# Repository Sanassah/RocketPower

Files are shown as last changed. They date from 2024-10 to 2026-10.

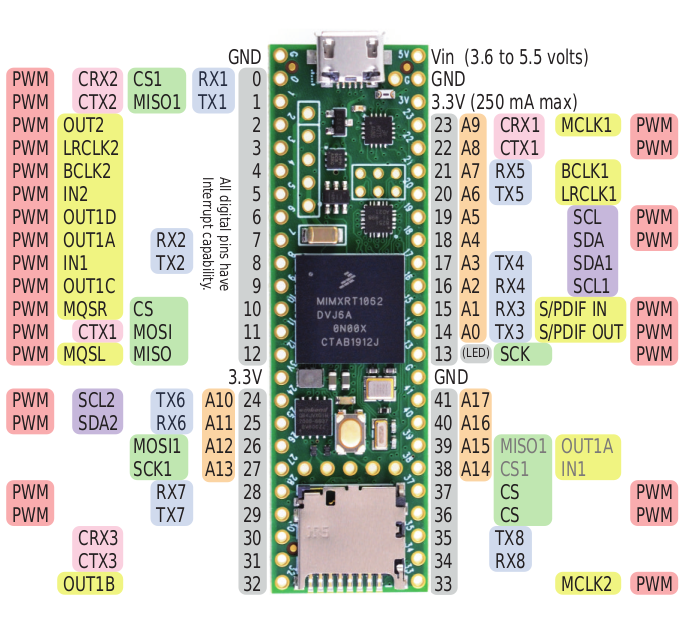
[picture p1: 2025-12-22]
Documentation/TechnicalDoc/Teensy4.1_Pinout.png

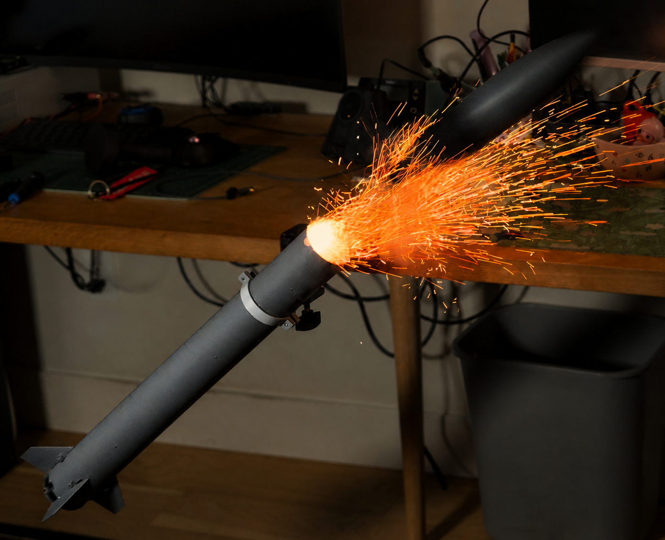
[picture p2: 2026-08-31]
Media/Linkedin_Post2/ThumbnailLinkedInpost2.png

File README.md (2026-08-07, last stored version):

<div align="center">

# 🚀 RocketPower

### A ground-up model rocket build — PCB design, CAD, systems simulation, and control systems.

RocketPower rocket render






</div>

---

## About

This is where I track progress on a model rocket build — avionics included — showcasing work in PCB design, CAD, systems simulation, and control systems.

**[→ Flight Procedure](./FLIGHT_PROCEDURE.md)** — step-by-step instructions for bench checkout, arming, launch, recovery, and post-flight data review, plus hardware-in-the-loop testing before you fly.

---

## Media

<!-- Swap these placeholders with real captures as the build progresses -->

Watch the launch (https://youtube.com/watch?v=PLACEHOLDER)

<p float="left">
  
  
  
</p>

---

## Build Log

| Date | Milestone |
|---|---|
| 2025 | Flight computer schematic complete |
| June 2026 | First avionics bench test |
| TBD | First flight |

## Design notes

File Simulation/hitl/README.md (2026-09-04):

# HITL (hardware-in-the-loop) testing

Runs the **real, compiled** flight firmware — `StateMachine`, `BackupDeploy`,
`AttitudeController`, `FinController`, `PyroController`, all byte-identical
to the flight build — on the actual Teensy 4.1, fed synthetic sensor data
from `RocketPowerSim.slx`'s 6DOF/aero model in real time, with the real fin
commands it computes closing the loop back into the simulated aero/actuator
response. This is what `config.h`'s pre-flight checklist means by "validated
in simulation (closed-loop)" before ever sending `ATTITUDE_CONTROL_ENABLE`
for a real flight — open-loop telemetry replay can't test this because
there's nothing for a replayed fin command to act on.

**One model, one switch.** `RocketPowerSim.slx` handles both plain
simulation and HITL now — double-click the **"HITL Mode Select"** Manual
Switch on the canvas to flip between them. It defaults to Normal Sim (no
hardware needed, same behavior as before HITL existed); flip it to HITL
only when you actually want a Teensy in the loop.

## What's real vs. simulated (in HITL mode)

| | Real | Simulated |
|---|---|---|
| Control code (state machine, attitude PID, fin allocation/clamping, pyro logic) | ✅ actual Teensy, actual compiled firmware | |
| Sensors (IMU, baro, high-g accel) | | ✅ injected over serial, from the 6DOF plant |
| Rigid-body dynamics, aero, servo lag/rate-limit | | ✅ `RocketPowerSim.slx`, unmodified downstream of the switch |
| Fin servos, pyro MOSFETs, SD card, LoRa | ✅ real hardware (harmless on a bench with no ematches/props attached) | |

## One-time setup

1. Flash the HITL build (not the flight firmware):
   ```
   cd FlightComputer
   pio run -e rocketpower_hitl -t upload
   ```
   This is a separate PlatformIO environment (`platformio.ini`) — the
   default `rocketpower` env (real flight firmware) is untouched by any of
   this.
2. Find the Teensy's **second** USB serial port (`SerialUSB1` on the device
   side) in Device Manager — it shows up as a second "USB Serial Device"
   alongside the one you already use for the ground station. The first port
   still carries normal command RX and the existing telemetry mirror
   completely unmodified — you can have the real GroundStation app
   connected over it and watch a HITL run live at the same time.
3. Open `RocketPowerSim.slx`, go inside the **"HITL Bridge"** subsystem,
   double-click `TeensyBridge`, and set `ComPort` to that second port.

## Running

- **Plain simulation**: leave "HITL Mode Select" at its default (Normal
  Sim) and run the model exactly as before — nothing about this changed,
  no hardware involved, same speed.
- **HITL**: double-click "HITL Mode Select" to flip it to HITL, then run.
  It runs in **real time** — `TeensyBridge` paces itself to wall clock
  every step, because the firmware's own safety timing (liftoff-confirm,
  apogee-detect window, backup-fire delay) is driven by the Teensy's
  hardware `millis()`, which nothing here can override (see the header
  comment on `SensorInjectPacket` in
  `FlightComputer/src/telemetry/Packet.h`). A 30s simulated flight takes
  ~30s.

`tout`/`pos_log`/`q_log` land in the base workspace exactly like before, so
`animate_flight.m` works unchanged either way.

To exercise ARM → liftoff → apogee → landed in HITL, send the same
`ARM`/`DISARM`/`FIRE_PYRO` commands you'd use from the ground station, over
the Teensy's **first** serial port, at whatever point in the run you want
them to take effect — the state machine reacts to them exactly as it would
in flight. Active fin control is a separate opt-in from ARM — send
`ATTITUDE_CONTROL_ENABLE` (works any time before liftoff, survives ARM) or
`ATTITUDE_DEMO_ENABLE` (takes effect in `IDLE` or `ARMED`, no need to arm
first) if you want the fins to actually respond.

### Debug scopes (inside "HITL Bridge")

- **"HITL Firmware State"** — the real firmware's own `FlightState` this
  step (`0`=IDLE, `1`=ARMED, `2`=POWERED_ASCENT, `3`=COAST, `4`=APOGEE,
  `5`=DESCENT, `6`=LANDED, `-1`=no response yet). Scope it alongside
  `rollCmd`/`pitchCmd`/`yawCmd` (`HITL Bridge`'s own outputs, or tap them
  where they feed the `Mode Switch N` blocks at the top level) if a command
  looks like it's still moving when you think it shouldn't be — this
  model's scopes plot against *simulation* time, while GroundStation's
  display is timestamped off the Teensy's own `millis()`, so
  cross-referencing "what I saw in GroundStation" against a Simulink
  scope's x-axis isn't reliable. The state output settles that directly: a
  command can only still be actively changing while state reads `2`
  (`POWERED_ASCENT`) or `3` (`COAST`).
- **"HITL Sensors (highg, tiltDeg, altitude, vertVel, gyro)"** — the raw
  plant-side signals `TeensyBridge` derives from the sensor stream:
  `highg` (1x3, g's, the exact specific-force vector sent to the firmware
  — same thing `StateMachine`/`BackupDeploy` threshold on via its
  magnitude), `tiltDeg` (angle from identity quaternion, not necessarily
  "from vertical" — see `TeensyBridge.m`'s class header), `altitude` (m,
  up-positive), `vertVel` (m/s, up-positive), `gyro` (1x3 rad/s). Valid
  every step regardless of whether the firmware actually responded, since
  they're computed straight from the injected sensor state, not the reply
  — useful for isolating a plant/physics issue from a firmware/control-loop
  one (e.g. watching whether `highg`/`tiltDeg` misbehave the same way even
  with `ATTITUDE_CONTROL_ENABLE` never sent, which points at
  `RocketPowerSim.slx`'s own aero model rather than anything in
  `FlightComputer/`).

## How the bridge works (`TeensyBridge.m`)

Lives inside the **"HITL Bridge"** Enabled Subsystem (quat/gyro/Xe in,
roll/pitch/yaw out), which only actually runs while "HITL Mode Select" is
set to HITL — see "Why an Enabled Subsystem" below for why that matters.
Each discrete step (default `Ts = 0.01s`, matching the firmware's real
100Hz loop):
1. Paces to wall clock.
2. Packs quaternion + body rate + position (derived from the `6DOF
   (Quaternion)` block's outputs — see the port mapping below) into a
   `SensorInjectPacket` and writes it to the Teensy.
3. Blocks for one `HITLResponsePacket` back — the real firmware's actual
   decision, fin clamping included.
4. Recovers pre-allocation roll/pitch/yaw commands from the 4 real per-fin
   degrees (`CH1=S, CH2=E, CH3=N, CH4=W` — see `AttitudeController.h`).

At the top level, each axis has a `Switch` block picking between "HITL
Bridge"'s recovered command and the model's own original PID output
(`Sum`/`Sum2`/`Sum3`), controlled by the same "HITL Mode Select" signal —
either way the result feeds the same actuator chain (`15deg sat` →
`1000deg/s` → `Servo lag (τ=15ms)` → moment/aero chain), unchanged.

### Why an Enabled Subsystem, not just a switch downstream

`TeensyBridge` opens its serial port **lazily**, on its first real
`stepImpl()` call, not in `setupImpl()`. This was a deliberate fix, and
matters if you ever restructure this: `matlab.System`'s `setupImpl` runs
once during Simulink's initialization phase for **every** block in the
diagram, *including* ones inside a currently-disabled Enabled
Subsystem — confirmed empirically. An Enabled Subsystem's enable signal
only gates `stepImpl`, not one-time setup. So if the port were opened in
`setupImpl` instead, a plain Normal Sim run would still require the Teensy
plugged in and running `rocketpower_hitl`, defeating the entire point of
the switch. Wrapping "HITL Bridge" in an Enabled Subsystem (rather than
just switching its output downstream, with the subsystem always running)
is what makes `stepImpl` — and therefore the port-open — only ever happen
when actually enabled.

### "roll"/"pitch"/"yaw" axis convention

This model (see `Constants.m`'s own header comment, `"spin about z = your
'yaw'"`) uses a **drone-style** convention: `"roll"` and `"pitch"` are the
two transverse-tilt channels (`Fin Moment Arm Roll`/`Pitch`, gain
`Cn_alpha`), and `"yaw"` is spin about the rocket's own longitudinal axis
(`Rocket Diameter2`, gain `Cl_delta` — confirmed by tracing each `*deg sat`
block forward to its moment-arm gain).

`FlightComputer/src/config.h`/`AttitudeController.cpp` use this SAME
convention (previously they used the opposite, standard-aerospace one,
where "roll" is the spin axis) — see config.h's axis-naming comment above
the `ATTITUDE_ROLL_RATE`/etc. macros. So each `Mode Switch N` block wires
`HITL Bridge` output `i` to actuator row `i` — a plain name-to-name mapping
is correct.

**This matters if you ever touch either side's axis convention again**: a
same-named-but-wrong mapping is silently wrong, not an error — it applies
the firmware's spin correction as a tilt moment and one of its tilt
corrections as a spin moment, so the controller can never actually reduce
the real error on 2 of 3 axes. That looked exactly like "the controller
won't converge" (saturating, growing commands), with no error thrown
anywhere. If you rename an axis on either side, re-derive whether the
mapping needs to go back to an explicit physics-based remap instead of
row-to-row.

### `6DOF (Quaternion)` output port mapping

Not documented anywhere in the model — empirically confirmed by probing a
live run against `Constants.m`'s own `eul_0`/`pm_0` initial conditions
(out3 matched `eul_0` exactly; out7 matched `pm_0` exactly; out4 matched
the quaternion equivalent of `eul_0`'s rotation) and, separately, by
differentiating every 3-wide output against every other over a real
flight:

| Port | Signal | Used by the bridge? |
|---|---|---|
| out1 | `Ve` — world-frame **velocity** (confirmed: `d(out2)/dt ≈ out1` almost exactly over a full flight) | not used directly |
| out2 | `Xe` — position `[x y z]`, m. **`Xe(3)` is UP-positive** (confirmed empirically against a full ascent/descent run — apex altitude and a clean positive→negative vertical-velocity crossing right at apex). This is *not* the NED Z-down convention `animate_flight.m`'s own `alt = -pos(:,3)` comment describes for `pos_log` — that variable evidently goes through additional processing this bridge doesn't touch (it taps out2 directly) | ✅ → altitude (`Xe(3)`, no negation); differentiated twice (world velocity, then world acceleration) for `vertVel` and body-frame kinematic accel |
| out3 | Euler angles, rad | not used |
| out4 | quaternion `[w x y z]` | ✅ → `quat_w/x/y/z`; also used to rotate world-frame quantities (acceleration, gravity) into body frame |
| out5 | DCM (quaternion→DCM) | not used |
| out6 | `Vb` — body-frame velocity | not used |
| out7 | `Wb` — body angular rate, rad/s | ✅ → `gyro_x/y/z` |

**The `6DOF (Quaternion)` block has no acceleration output at all.** Body-
frame kinematic acceleration is derived by the bridge itself: double-
differentiate `Xe` (world position) to get world-frame acceleration, then
rotate into body frame with the quaternion via `quatRotateWorldToBody.m`
(the same helper used for gravity, below). This replaced an earlier,
wrong version of this bridge that fed `out1` in as if it were acceleration
— it isn't, it's velocity, and using it as acceleration meant the firmware
was receiving a velocity value mislabeled as `lin_accel`/used for `highg`
for a while. If you ever add a new signal from this block, verify what it
actually is (e.g. by differentiating it against known IC's or another
candidate) rather than trusting a name or a guess — this model doesn't
label its own ports.

Gravity in this same world frame is `[0;0;-g]` (pulls toward -Z, matching
the "+Z is up" finding above) — used to project gravity into body frame for
`highg`. Getting this wrong doesn't just flip `highg`'s per-axis sign, it
corrupts its **magnitude** too whenever the airframe isn't sitting still or
perfectly vertical (the kinematic-accel and gravity-projection vectors stop
being parallel), and magnitude is exactly what `StateMachine`/
`BackupDeploy` threshold on (`highg_mag_g`) — see
`quatRotateWorldToBody.m`'s header.

**Getting the altitude sign wrong is a silent, nasty failure mode**, not a
crash: it doesn't break liftoff detection (that's magnitude-only), but it
inverts the sense of `COAST`'s zero-crossing check, so a real ascent-to-
descent transition reads as vert_vel going negative→positive instead of the
positive→negative the firmware is watching for. The state machine then gets
stuck in `COAST` for the rest of the flight, however long it runs, with no
error anywhere — it looks exactly like "the state machine isn't working"
rather than "the plant-side sign is backwards." If a flight visibly climbs
and comes back down but `state` never leaves `COAST`, check this first.

## Troubleshooting

- **"nothing on the dashboard" in GroundStation, even though it's
  connected**: make sure you're connected to the Teensy's *first* USB
  serial port, not `SerialUSB1`. Also make sure you reflashed after any
  firmware update — `SensorManager::update()` falls back to a safe
  "resting on the pad" default and keeps the loop (and telemetry) running
  even before `TeensyBridge` connects.
- **`Function 'serialport' not supported for code generation` when running
  the model**: `TeensyBridge` must run in interpreted execution, not the
  MATLAB System block's default code-generation mode. Double-click it
  (inside "HITL Bridge"), open its block parameters, and set "Simulate
  using" to "Interpreted execution".
- **A HITL run seems to hang, or errors immediately about a port**: check
  `TeensyBridge`'s `ComPort` (inside "HITL Bridge") actually matches the
  Teensy's *second* port right now — it can change across replugs/reflashes.
  The error message lists what's actually available if it can't find it.
- **Started a HITL run, want to go back to plain simulation**: just flip
  "HITL Mode Select" back and rerun — no other cleanup needed.

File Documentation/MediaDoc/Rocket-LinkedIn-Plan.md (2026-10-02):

# RocketPower — LinkedIn Posts

4 posts. Post 1-3 are ready now. Post 4 is reserved, write it after the
actual flight (two branches below, use whichever happened). Only the
`[MEDIA: ...]` lines (and the `[DATE]`/`[X]` fields in post 4) are
placeholders.

---

## Post 1

In 2024, I started designing a custom flight computer for a rocket 🚀
Then I didn't touch it again for almost a year.

My capstone project was a drone built from scratch with a great team.
When it ended, I missed the challenge, so I leaned on my background in
rocketry at Concordia and started something of my own: an active
fin-control rocket, custom PCB and flight control code in C++. I got as
far as the MCU section of the schematic before life took over.

Graduation, a trip through Asia, a new job, moving out of my parents'
house. A year passed. I'd open KiCad, feel discouraged by the amount of
work ahead, and close my laptop.

The itch never went away, and I came back to it in 2025. I bought a $200
refurbished 3D printer, a soldering station, and a power supply. I had to
relearn electronics from books, forums, YouTube, and PJRC. I often felt
the need to go on Fiverr and hire an EE for a review of my work, but I
decided to trust myself, and earned that trust through 15 revisions 😆

Then came the layout, the hardest part. Fitting that many sensors, servo
channels, telemetry, camera, GPS, EMI shielding, power conversion, and
pyro channels into a 50mm diameter was the challenge, I wasn't willing to
compromise. I picked a BGA MCU (MIMXRT1062) on purpose, smaller footprint
and more of a headache. A 2-layer board wouldn't work. I went to 4 layers
and rewrote the whole architecture more than once. There were nights I
stared at the ratsnest wondering if I'd picked a form factor that just
didn't work.
Then, at some point, it did.

[MEDIA: photo of the $200 refurb 3D printer / solder station setup or the
early schematic, plus a PCB layout screenshot showing the density]

#engineering #aerospace #pcbdesign #embeddedsystems

---

## Post 2

The preassembled board finally arrived ($400 later). It was pure magic right up until I plugged it in... then crickets. 
Total radio silence: no COM port, no USB handshake, no signs of life.

I'd ordered it through PCBWay, generated the Gerbers while vacationing in Peru, and managed supplier Q&A from 
there (really impressed by their service btw). But one design mistake at that stage meant flushing money and effort down 
the drain. So when it showed up dead, my stomach dropped.

Cue two nights of full-blown engineering existential dread. At one point, I was staring down the barrel of manually 
reworking microscopic BGA pads. But after sleeping on it, I stopped overthinking and audited the schematic line by line.

Turns out, I didn't need surgical BGA mastery. I had accidentally designed the reset button to be hard-wired to ground. 
Basically, I gave my own flight computer a perpetual coma. One quick trace surgical strike with an X-Acto knife later, 
I plugged it in and heard the glorious Windows USB connect chime. I don't think a single sound has ever brought me that much inner peace.

[MEDIA: macro shot of the knife-cut trace on the real board, plus a photo
of the board arriving/unboxing]

#pcbdesign #embeddedsystems #debugging

---

## Post 3

While the board was busy pretending to be dead, the rest of the rocket had
to keep moving in parallel.

Fusion 360: carbon fiber rods, a 3D-printed body, 4.4g servos on
3D-printed fins, all self-taught, including the hard way why revision
control matters (RIP a few corrupted CAD files).

Procurement became its own side-quest, motors, cameras, LiPos, ejection
charges, e-matches, telemetry, while I built the ground station in
parallel: the classic "one quick fix" that ends at 3AM with the terminal
staring back. Sensors blinked to life one by one, each a small dopamine
hit, minus the time I shorted a connector and blew a fuse (protection
circuitry: confirmed working).

The real test was 6DOF simulation in Simulink, real mass/CG/CP from
Fusion and OpenRocket, tuning fin control before the flight computer ever
touched real hardware. Handling the airframe also exposed a flimsy
direct-drive fin mount, fixed with a tiny press-fit bearing, and pushed
me to make the fins fail safe on a dead servo.

Then hardware-in-the-loop: real flight computer, real control code, wired
straight into the simulation. Watching the 6DOF animation and the ground
station agree on every flight phase live was the best moment of this
project yet. Honest caveat: no RTOS, so a stray SD card hiccup at the
wrong moment is a risk I'm flying with, eyes open.

The whole thing is assembled and sitting in front of me. Still doesn't
feel real.

Next up: finding a launch site. To be continued.

[MEDIA: 20s HITL + ground station video (see PreflightVideo-ShotList.md)
as the primary post video, plus a close-up photo of the bearing mod as a
secondary image if LinkedIn's carousel allows more than one attachment]

#cad #groundstation #hitl #controlsystems #aerospace

---

## Post 4 (write after the actual flight, use whichever branch happened)

**If it flew clean:**

[DATE]. After [X] months of nights, the rocket flew.

Custom flight computer, custom PCB, active fin control, hand-built ground
station, all of it ran like it did on the bench, just [X]m up instead of
on a table.

Apogee at [X]m, recovery [X]m from the pad. Every system worked.

Two years ago this was a notebook sketch. Today it's a flight log.

**If something went wrong:**

[DATE]. The rocket flew today, and it didn't go the way I planned.

[ONE OR TWO SENTENCES: what happened]

I'll tell that story in full, it's more useful than a highlight reel, and
everything else in this project failed once before it worked too.

[MEDIA: launch photo/video, ignition, ascent, recovery, plus a screenshot
of the actual telemetry plot from the flight]

#aerospace #rocketry #embeddedsystems

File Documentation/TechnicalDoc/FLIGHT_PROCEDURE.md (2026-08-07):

# Flight Procedure

Step-by-step operating instructions for the RocketPower flight computer and
ground station — bench checkout, pad procedure, launch, recovery, and data
review. For code/architecture docs see `FlightComputer/` and
`GroundStation/README.md`; this file is about *running* the system, not how
it's built.

---

## 0. What you're working with

- **Flight computer**: custom PCB (`FlightComputer/`), programmed via the
  Teensy 4.1 toolchain. Runs autonomously once powered — it does not need
  the ground station connected to fly correctly. The ground station is for
  visibility and manual commands (arm, fire, calibrate), not for the flight
  logic itself.
- **Ground station** (`GroundStation/`): the PyQt6 app (`python main.py`).
  Three pages, left sidebar: **OVERVIEW** (GPS map, trajectory, 3D
  orientation, pyro/continuity/arm panels), **TELEMETRY** (sensor status,
  commands, event log), **DATA TOOLS** (post-flight `.BIN` → CSV/MATLAB
  converter).
- **Two ways to connect the ground station**: directly via USB to the
  flight computer (bench testing — fast, but only works with a cable
  attached), or via a ground-side LoRa receiver dongle at **9600 baud**
  (the actual flight link, works untethered). Pick the right COM port/baud
  in the sidebar before connecting.

---

## 1. Bench checkout (do this before you ever go to the pad)

1. Flash the real flight firmware if you haven't recently:
   ```
   pio run -e rocketpower -t upload
   ```
2. Power the flight computer and let it boot. It self-tests every sensor
   and the SD card, then halts (flashing the status LEDs) if the IMU or
   barometer failed — those two are flight-critical and it won't proceed
   without them. Everything else (GPS, accelerometer, power monitor, SD)
   is allowed to fail at boot and just gets flagged, not fatal.
3. Connect the ground station over USB and open the **TELEMETRY** page.
   Check the **STATUS** section: IMU / Barometer / Accelerometer / GPS
   Module / Power Monitor should all read **OK**, and **SD Card** should
   read **IDLE** (present, not yet recording — recording starts
   automatically once you arm, see §3) or **RECORDING** if a card was
   present at boot (it auto-opens a log immediately, see §4).
   - If SD reads **NO CARD**: insert one and press **Start Log** in the
     SD CARD section of the command panel to retry — it doesn't
     re-poll on its own (see `DataLogger::cardPresent()`'s doc comment
     for why).
4. Check pyro continuity on the OVERVIEW page's continuity panel — each
   channel should show continuity if an ematch is connected (or "open" if
   deliberately left disconnected for a bench test).
5. Optional: run a fin servo preflight sequence (TELEMETRY page → FIN
   SERVOS section → **PREFLIGHT**) to visually confirm all 4 channels move
   correctly before you close up the airframe.
6. Optional: toggle the camera on/off once (CAMERA section) to confirm the
   UART link is alive — it also self-probes at boot and reports to Serial.

---

## 2. Pad procedure

1. Mount the rocket vertically on the pad, **stationary** — the next step
   calibrates the barometer against whatever altitude it's sitting at
   right now, so don't move it after this point.
2. Connect the ground station via the LoRa link (not USB, unless you're
   doing a tethered test) and confirm telemetry is flowing (state should
   read **IDLE**, sensor values should look sane, GPS should have a fix if
   you want position data during descent/recovery).
3. Press **ARM** (ARM CONTROL section, or the dedicated arm panel on
   OVERVIEW). This asks for confirmation, then:
   - Arms the pyro channels (fire commands only work while armed).
   - Re-calibrates the barometer at the pad — this is why the rocket needs
     to be stationary and already in its final position.
   - Starts the camera recording, if not already running.
   - SD logging is already running by this point (started automatically at
     boot) — arming doesn't gate it, it's just confirmed by the SD status
     row.
4. Double check the SD status row now reads **RECORDING** and pyro
   continuity still looks correct before proceeding — this is your last
   easy checkpoint before the log starts mattering.

---

## 3. Launch

- If your motor uses **electronic ignition**: press **Fire CH 1 —
  Ignition** in the IGNITION CONTROL section. This is a real, irreversible
  action (confirmation dialog says so) — it's the actual launch trigger.
- If you're hand-lighting the motor: ARM is still required first (it's
  what enables liftoff detection and parachute deployment logic), but
  ignition itself happens outside the electrical system.

From here the flight computer runs itself — you're a spectator with an
abort/backup option (§5), not a pilot.

---

## 4. What happens automatically in flight

The state machine (`StateMachine.cpp`) transitions on its own based on
sensor data, no ground input needed:

| Transition | Trigger |
|---|---|
| ARMED → POWERED_ASCENT | High-g accel > 2.5g, held for 100ms (liftoff) |
| POWERED_ASCENT → COAST | High-g accel drops below 1.0g (burnout) |
| COAST → APOGEE | Vertical velocity crosses from + to -, held for 200ms |
| APOGEE → DESCENT | Immediate — parachute (CH2) fires automatically here |
| DESCENT → LANDED | Altitude stable within 2m for 10 continuous seconds |

Also automatic: the camera stops recording on LANDED, the SD log flushes
on every state change (bounding data loss) and closes fully on LANDED,
and telemetry keeps transmitting at 1Hz over LoRa the whole time
regardless of what the ground station is doing.

---

## 5. If something looks wrong mid-flight

- **Parachute didn't seem to deploy** (altitude/velocity on the ground
  station not showing a slow-down after apparent apogee): press
  **Fire CH 3 — Backup** manually. This works any time after ARM, not
  just during DESCENT — it's a manual override independent of the state
  machine.
- **Telemetry drops out**: the flight computer doesn't care — it keeps
  flying/logging/recording regardless of whether the ground station is
  receiving. Nothing to do but wait for the link to come back (or recover
  by GPS coordinates / last known position).

---

## 6. Recovery and data review

1. Retrieve the rocket. The SD log is already closed and safe (closed
   automatically on LANDED) — no need to power it off first, but do so
   before opening the airframe to swap the card.
2. Pull the SD card, find the newest `FLTxxxxx.BIN` file.
3. Convert it for analysis — either:
   - **Ground station GUI**: DATA TOOLS page → Browse → select the file →
     check CSV and/or MATLAB → **Convert & Save As...**.
   - **Command line**: `python GroundStation/tools/log_convert.py FLTxxxxx.BIN`
     (writes CSV and, if `scipy` is installed, `.mat` next to the input
     file by default).
4. The ground station's own local CSV log (separate from the flight
   computer's SD card — see the "⏺ REC" button in the TELEMETRY page's
   event log header) captured whatever telemetry it received live, useful
   as a cross-check but lower rate/resolution than the onboard SD log.

---

## Quick troubleshooting

| Symptom | Likely cause |
|---|---|
| FC halts at boot, LEDs flashing | IMU or barometer failed — check wiring/power before anything else |
| SD status stuck on "NO CARD" after inserting one | It doesn't auto-repoll while idle (by design — see §1.3); press **Start Log** |
| Telemetry rate unstable / bounces to 0 | Check `USB_SERIAL_BINARY_MIRROR`/reflash status if using USB |
| USB shows no telemetry at all | `USB_SERIAL_BINARY_MIRROR` must be `1` in `config.h` for a direct-USB ground station connection |
| Ground station won't connect | Right COM port? Right baud (9600 for the LoRa dongle, doesn't matter much for direct USB)? |

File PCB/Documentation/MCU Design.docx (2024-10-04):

SCSD-LP-EPS-004-A

# MCU Design

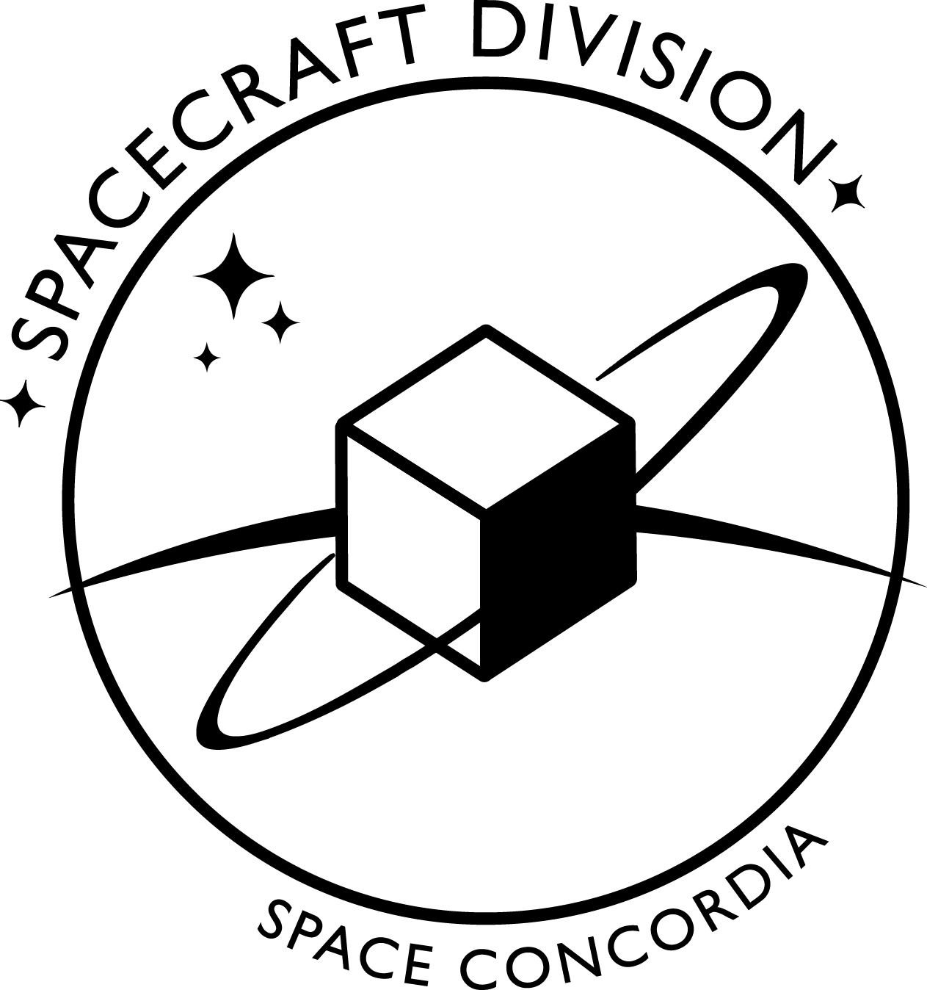
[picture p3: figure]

Prepared by

Gabriel Dubé

Electrical and Power System Lead

Feb 1, 2023

# Revision History

Date | Revision | Changes
5-Feb-2023 | A | Initial Release

# Table of Contents

Revision History 2

Table of Contents 3

References 4

Abbreviations and Definitions 5

Introduction 6

MCU 7

Power 7

Crystals 13

Internal Peripherals 14

GPIOs 15

I/O Isolator 16

Debugging 18

PCB Layout 24

Appendix A 24

# References

[1] CCP- Subsystems - POWER - Design - SC-ODIN-100, Spacecraft Electronics - SPEAR-M7 - Rev A [internal document on Google Drive], “SCH-SCSD20-EPS-001-A”. Available from: https://drive.google.com/file/d/1Hjo98G_CQyjNqB3IPMDdYu_njFDT6Aj3/view?usp=sharing

[2] Marki - RFTOOLS [website], “LC Filter Design Tool”. Website link: https://rf-tools.com/lc-filter/

[3] CUBICS - ELEC - Learning Resources - Learning Package [internal document on Google Drive], “Power”. Available from: https://docs.google.com/document/d/1pKWWyXrTBQWnoESd13gtv7d2UHne3ekIcaZ94zOk2eo/edit?usp=sharing

[4] CUBICS - ELEC - Learning Resources - Learning Package [internal document on Google Drive], “Peripherals Design”. Available from: https://docs.google.com/document/d/1Y1tGknWdWDa7ZUS9X4p9ahikzXoImTVWvahNcEV4DlE/edit?usp=sharing

[5] Microchip datasheet, [PDF document], “SAM E70/S70/V70/V71 Data Sheet”. Link to document: https://ww1.microchip.com/downloads/aemDocuments/documents/MCU32/ProductDocuments/DataSheets/SAM-E70-S70-V70-V71-Family-Data-Sheet-DS60001527.pdf

[6] CUBICS - ELEC - Design [internal document on Google Drive], “Breakout Boards”. Available from: https://drive.google.com/drive/folders/1IolXB_eUfjbBWtSN64kAr6lkOlDXZvvk?usp=share_link

[7] CUBICS - ELEC - Learning Resources - Learning Package [internal document on Google Drive], “Serial Communication”. Available from: https://docs.google.com/document/d/1fTaHIaRPVIfN-HuLPqiPyxERU_JW75ML_xxsHw8t4RE/edit?usp=share_link

[8] CUBICS - ELEC - Learning Resources - External Resources [internal document on Google Drive], “PCB Design Tutorial by Dave Jones”. Available from:

https://drive.google.com/file/d/1sQq1nrMSX9F_TmR0TZrsZLF_wutw7tkj/view?usp=share_link

[9] Analog Devices [Website], “Crystal Considerations with Maxim Real-Time Clocks (RTCs)”. Available froom:

https://www.analog.com/en/design-notes/crystal-considerations-with-maxim-realtime-clocks-rtcs.html

# Abbreviations and Definitions

Terminology | Definition
ADC | Analog to Digital Converter
ADCS | Attitude Determination and Control System
CAN | Controller Area Network
CDH | Command and Data Handling
CM | Common Mode
CSA | Canadian Space Agency
DM | Differential Mode
DNP | Do Not Place
ESD | Electrostatic Discharge
GPIO | General Purpose Input/Output
LED | Light Emitting Diode
LVDS | Low-Voltage Differential Signaling
MCU | Micro Controller Unit
RTC | Real Time Clock
SC-FREYR | Fermentation R- Extraterrestrial Yeast R-
SPEAR-M7 | Flight computer of SC-ODIN
SPI | Serial Peripheral Interface
TVS | Transient voltage suppressor
UART | Universal Asynchronous Receiver-Transmitter
UART | Universal Synchronous and Asynchronous Receiver-Transmitter
USB | Universal Serial Bus

# Introduction

MCU design is one of the more complex aspects of designing PCBs. Margins for errors are much smaller and proper layout rules are crucial. With that said, if done following a precise set of rules and conventions, MCU design can be fairly simple to adapt from one design to another as the procedure stays more or less the same for most MCU that will be used in FREYR and even future projects. This document will go in depth on those rules and how they can be applied across virtually any MCU design, from proper power and grounding to supporting hardware and ending on layout rules given how important they are.

Throughout this document, two MCU in particular will be used as examples: the ATMEGAS64M1-MA-HP and the ATSAMV71Q21B-AAB. This will offer both extremes in terms of QFP package, with the ATmega having 32 pins and the ATSAM having 144. This is particularly relevant for SC-FREYR since the new architecture will utilize both a 144 pin MCU and many 32 pin MCUs. Knowing how to properly implement both of these will be crucial to any redesign from SC-ODIN.

# MCU

## Power

MCU are one of the more complicated devices to power. They are generally very sensitive to noise, spikes and any other disturbances on the power lines. They even have detailed power down and power up sequences that need to be supplied by the chosen converter. Proper grounding techniques will also be explored in this section as it often is a major source of noise when improperly done. Filtering will also be explored in this section, although not in depth given the complexity that it can reach. This section will particularly look at the implementation of the ATSAM on the SPEAR-M7, the flight computer of SC-ODIN.

The first step in any MCU design, or any design in general, is to take a look at the datasheet and extract the relevant information for each step of the implementation. For power, it is very good practice to show on the schematic design the power requirements of the MCU, the power up sequence and the power down sequence. This can be seen on page three of reference [1] and on Figure 1 & 2 and should be present in any MCU design sheet for spacecraft electronics i.e. if it is going to space. This ensures that the chosen converter can satisfy the requirements set by the MCU, and also makes it easier to evaluate power consumption, noise generation and software requirements.

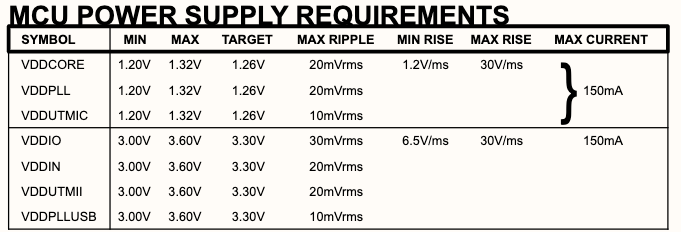
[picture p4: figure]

Figure 1: ATSAMV71 power requirements

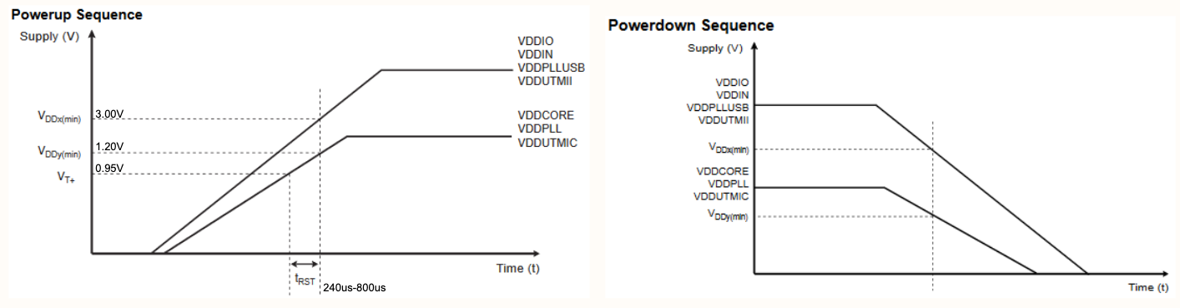
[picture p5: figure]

Figure 2: ATSAMV71 power up and power down sequence

EMI Filter

Before implementing any power regulation, it is necessary to ensure that the overall power input of the board is free of any noise from other parts of the electrical system. The way to ensure this is by implementing a power filter at the board power input. Since power filters can get very complex, only one type of filter will be explored in this section: the PI filter. It is a simple, low component count and bidirectional filter, which means it will filter the input as well as the output to prevent a design from inducing noise into the rest of the system. This filter is only really required for MCUs and RF designs, since they tend to be more noise sensitive and noise generating. Note that this is also only necessary for designs that are a part of a larger system, not for breakout board designs or isolated designs.

A basic PI filter requires three elements: one inductor and two capacitors. There are two main types of PI filter: the Chebyshev and the Butterworth. Although the Chebyshev tends to have steeper decline in the frequency domain near the cutoff frequency, it trades it off for a generally worse time domain response compared to the Butterworth, which is why the latter is the recommended design for MCU filters. They are typically arranged in the configuration seen on Figure 3. The variation in the inductor and capacitor values will dictate how the filter acts from Vin to Vout and vice versa. The convenient thing about this configuration is that if both capacitors have the same value, the symmetry makes it that the backwards frequency response will be the same as the forwards response.

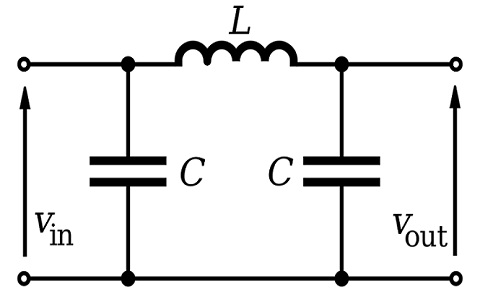
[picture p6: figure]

Figure 3: PI filter basic configuration

Figuring out the right values for any given application is the more challenging part of such filters, especially when forming RLC networks that can have high resonance. Fortunately, websites such as reference [2] can greatly help in finding those values. On this particular website, the PI filter is the equivalent of a lowpass butterworth 3rd order filter with shunt first topology. The desired cutoff frequency, input impedance and output impedance can be set to find the inductor and capacitor values. The impedance values are known from the specific design configuration that is being implemented, and the required cutoff frequency will be defined by the chosen MCU. At first, this looks fairly simple; evaluate the design to find the impedance values and check the data sheet for recommended cutoff frequency. Unfortunately, these filters are extremely sensitive to any type of parasitics, whether they are inductive, resistive or capacitive. This means that not only will the chosen inductance and capacitance value have a big impact on the frequency response, but the specific chosen components will as well. This is because all capacitors and inductors have parasitic effects, and some have more than others. Appendix A goes in depth on the design process of these power line filters and how to account for parasitics.

Power converter

Now that the power requirements are well defined and readily available on the schematic and that the input line is filtered, a power converter that matches the requirements can be chosen. The first choice that will be encountered when looking for a power converter is to choose between a linear regulator or a switching converter (also called buck converter). Reference [3] goes in depth about the difference between both, but for MCUs it is recommended to use buck converters. The next parameter to look into is voltage conversion. It needs to be able to take the board's power input, usually 5 or 3.3, and convert it to the required voltage. Although this may differ depending on the chosen MCU, the ATSAM requires a 3.3V and a 1.25V input. This means that if no 3.3V rail is available on the current design, two converters will need to be implemented. Another parameter that needs to be taken into consideration is the ripple factor of the converter. Going back to Figure 1, the datasheet will specify the maximum allowed ripple factor and the chosen converter needs to meet this requirement. Lastly, the selected DC/DC converter needs to be able to supply the required current from the MCU. This particular MCU, as seen in Figure 1, requires a total of 300 mA at maximum operation. It is good practice to choose a converter that can supply more than the required current to account for power loss and to reduce the margin of error.

For the SPEAR-M7 design, the selected converter was the EP5368QI. This step down DC-DC converter (another name for power converter) offers a low ripple factor, adjustable voltage output with a supply current of 600 mA. Three pins allow to set the voltage output of the converter, making it compatible for 3.3 and 1.25 volt conversion. On top of the required features, it also has short circuit protection, under voltage lockout and thermal shutdown. Figure 4 shows the implementation of this chip to convert the 3.3V input (input of the entire board) to 1.25V rail.

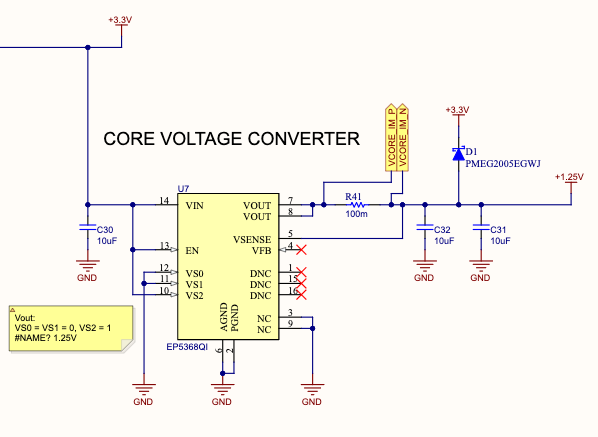
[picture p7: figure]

Figure 4: EP5368QI implementation on the SPEAR-M7

Providing the equation for voltage selection, like done in Figure 4 (pin VS0/1/2), is always good practice and makes it easier for the design reviewer to validate the design. It is important to note that current sensing is implemented using a shunt resistor, which should always be done for self sustaining designs. Refer the ADC section of reference [4] to understand current sensing. Another important thing to note is the presence of big decoupling capacitors, which are crucial to maintain low noise power rails. Lastly, D1 is a schottky diode which will protect the 1.25V line in case of a massive inductive spike that can occur from switching converters (read on schottky diodes).

One thing to note on page three of reference [2] is the VDDOUT pin on the ATSAM power block. The datasheet specifies that the MCU has an integrated voltage converter to provide the 1.25V rail. Although this can be used for ground equipment design, it is recommended to implement an external converter for space design for redundancy purposes. MCUs are very sensitive to radiation and even if the particular MCU chosen is radiation resilient, the internal converter is still subject to a higher risk of failure. External converters also tend to have better stability and noise reduction circuitry. It is still good practice to place a 0R DNP resistor in series to allow the use of the internal converter during testing or for other purposes. With that said, make sure the DNP is visible and listed in the 0R properties to avoid assembly errors.

Input Filtering

One last filtering stage is needed for MCU power input pins. As seen on previous designs, one 100nF capacitor should be added to every power input pin for proper decoupling. Some specific pins will need added filtering, most of the time in the form of an extra capacitor with a different value or an in-line ferrite bead. Ferrite beads are used a lot in Spacecraft’s design for their ease of implementation and great noise reduction properties (highly recommended to read up on ferrite if unfamiliar with the component). The pins that will require the extra filtering can be found in the datasheet. For the ATSAM chip, the datasheet is nearly 2000 pages long, so it might require some time to locate the relevant information. The data sheet of the ATSAM can be found at reference [5]. This is where the information about the recommended filtering can be found. More precisely, page 1873 and the following pages contain recommended capacitor, inductor and ferrite bead values for decoupling and filtering on the specific power pins. First, let’s look at the power block schematic symbol of the chip.

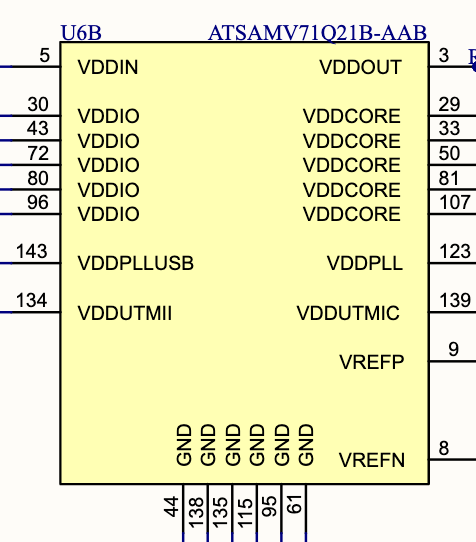
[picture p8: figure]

Figure 5: ATSAMV71 power block schematic diagram

The data sheet specifies the following connections: VDDCORE, VDDPLL and VDDUTMIC need to be powered by the 1.25V supply and VDDIN, VDDIO, VDDPLLUSB and VDDUTMII need to be powered by the 3.3V supply. VREFP and VREFN are used for the internal ADC, which will be looked into in another section of this document. VDDOUT is the internal power converter output, and should follow the previously mentioned implementation.

On page 1873 of the data sheet, the recommended filtering for each of these power pins is shown. VDDIO, VDDUTMII and VDDCORE all require a single 100nF capacitor on each pin. VDDPLLUSB, VDDPLL and VDDUTMIC all three require the 100nF capacitor, and a ferrite bead or inductor resistor combo in line with the input pin. For ease of component sourcing, an identical ferrite bead can be used on all three inputs. The data sheet recommends a 470R @ 100 MHz ferrite bead, but similar values can also be used. Lastly, an extra capacitor is required on the VDDPLLUSB line, either the recommended 4.7uF or other similar value used in the design. Figure 6 shows the final implementation of the power block for the ATSAMV71 chip. All some of the values present are based on part sourcing constraints, like the ferrite bead value.

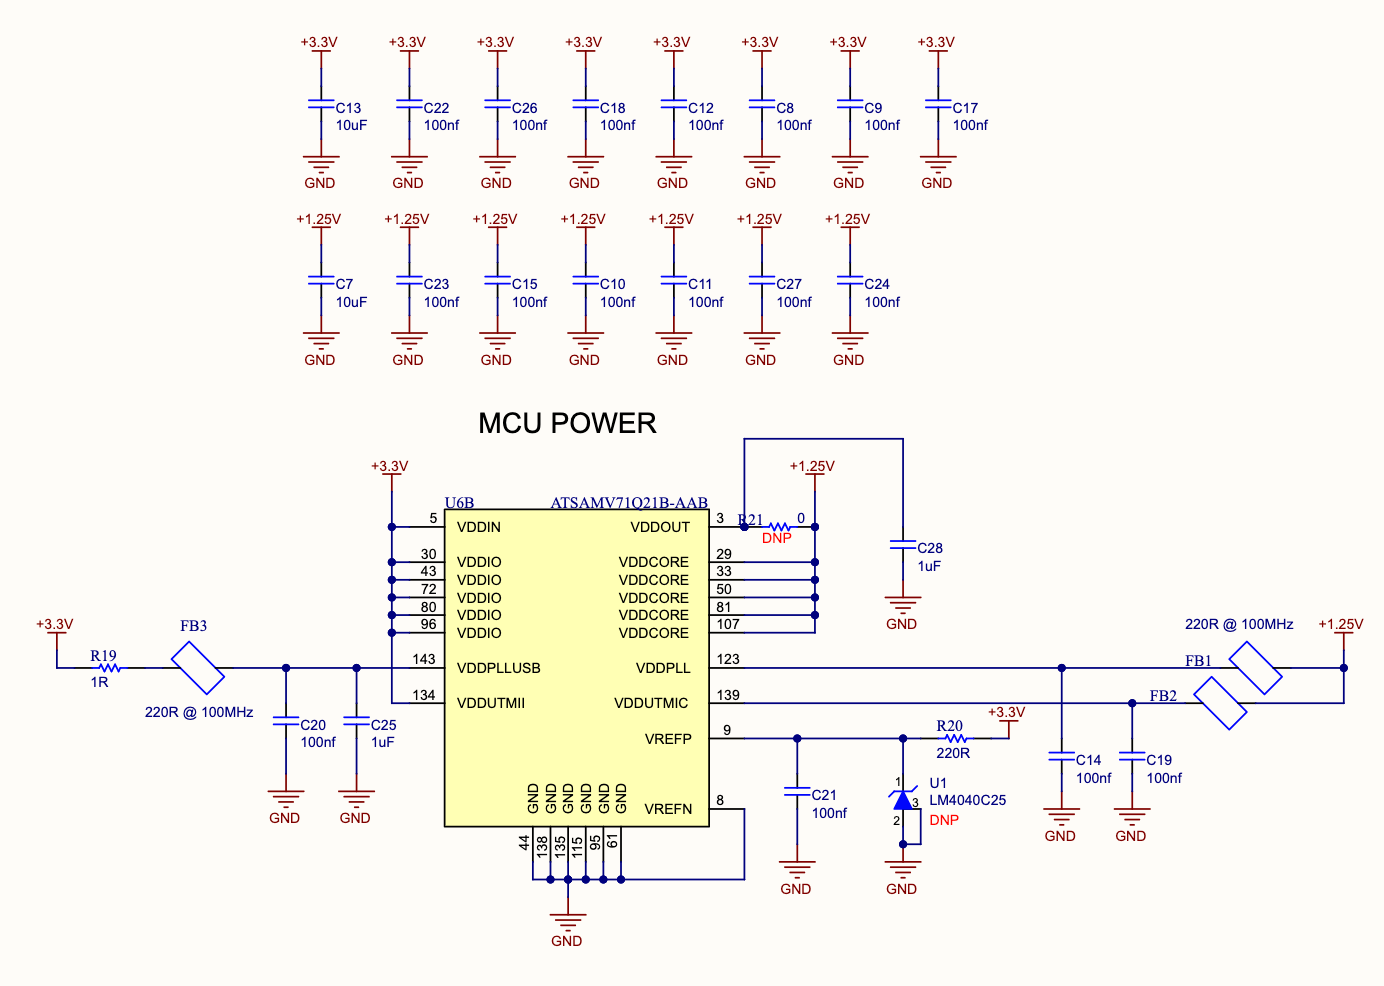
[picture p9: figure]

Figure 6: ATSAMV71 power block implementation

Important to note that for ease of reading, all 100nF decoupling capacitors are grouped away to not cram the schematic block. The will be assigned to a particular pin when doing the PCB layout. It is also recommended to have a 10uF bulk capacitor for every voltage net (one for 3.3, one for 1.8 and etc). One last thing to note is the presence of the 0 ohm DNP resistor on VDDOUT, which refers to the DNP resistor mentioned at the end of page 11.

To reiterate, each MCU will have specific power considerations, noise sensitivity and implementation recommendations. Small MCU are generally really simple to implement: some of them will only require a single 100nF capacitor and a ferrite bead between the main power and its power input pin. The goal of this section was to show a proper implementation of a large MCU, and the rules and conventions used can be applied to most designs. Adjustments need to be made following the manufacturers recommendations, but it will rarely be significant.

## Crystals

Crystals are an essential part of MCU design, since every single MCU requires either a crystal oscillator or an external clock generator. Some smaller package MCUs will even have an internal oscillator, but it is generally good practice to implement an external crystal if the pin count allows it. These oscillators can have multiple uses, but their main use is to generate stable and accurate clock signals. They are also commonly used to count time in RTCs.

Crystals are usually fairly simple to implement. MCUs have dedicated pins to connect the oscillator to, often marked with the prefixes X or OSC (might differ depending on the chosen MCU). Fortunately, crystals are bidirectional and can simply be connected in any orientation. Bigger MCU will have two sets of dedicated pins, one for high frequency oscillator and one for low frequency (usually marked HF and LF). The only element required when connecting a crystal is two capacitors going to ground on both leads of the crystal. This value will depend on the frequency of the crystal. Figure 7 shows the two crystals used on the ATSAMV71 and their implementation. Resistors may be added in series following the datasheet recommendation for max ESR and internal equivalent capacitance.

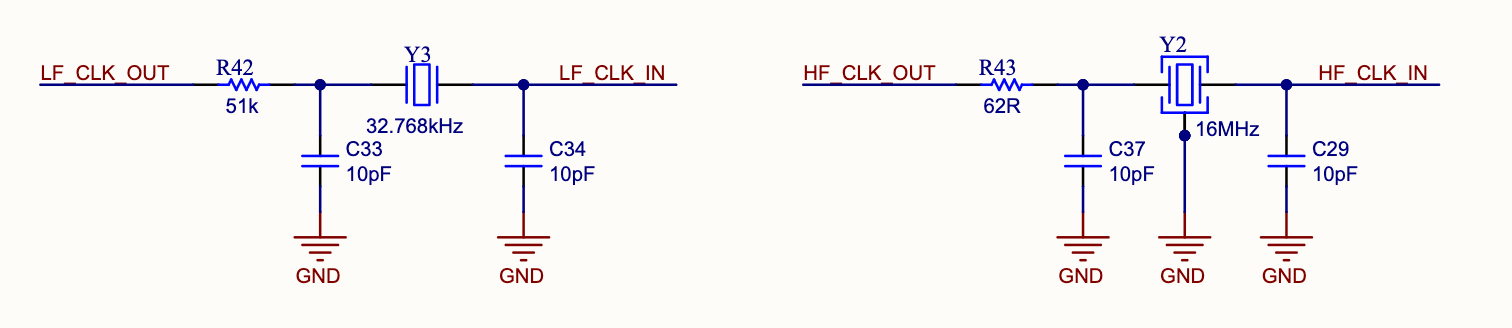
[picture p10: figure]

Figure 7: Crystal Oscillators implementation

The most challenging aspect of crystal oscillators is their PCB layout considerations, which will be discussed in another section of this document.

## Internal Peripherals

Many MCUs have embedded peripherals such as ADCs, RTCs, DACs and more. How many are included will often depend on the size of the package and the complexity of the MCU. They can be accessed through specific pins or even regular GPIO if the architecture allows it. This section will look at different types of internal peripherals, the advantages and disadvantages of them and how to properly implement them.

ADC

Almost every MCU has an internal ADC that is available to use. Depending on the size of the MCU, it might be single channel or multi-channel and the precision will vary with MCU complexity. All of the information concerning the internal ADC can be found in the MCUs datasheet. These have some advantages: they are easy to implement and don’t require any communication lines to function, unlike external ADCs. The disadvantage of them is that the number of channels is often limited and they can only be used to measure analog voltage close to the MCU itself, otherwise too much noise will be introduced.

Their implementation is usually very simple and similar to external ADCs: the MCU will have an analog VCC port and an analog GND port, which should both be kept separate from the main power and ground of the board following the design practice mentioned in reference [4] page 8. The MCUs datasheet will then specify which I/O can be used as an analog read pin. Large MCUs will offer multiple input channels and allow the user to access them through any GPIO, making the implementation really convenient. On the other hand, smaller MCU will have a restricted number of channels and might only be accessible through certain I/Os. If the number of I/O is too low for a required design, an analog switch or an external ADC should be considered. Last aspect of internal ADCs to consider is the voltage reference. Some MCUs will have internal selectable references that can be used for A/D operations, but some MCUs will also require an external voltage reference to be connected to a port, commonly named AREF (analog reference). If an external reference is required, components such as the LM4040 are simple to implement and will supply the appropriate voltage reference. Figure 8 shows the implementation of an internal ADC on the ATmega64 MCU which will be used throughout the design of SC-FREYR.

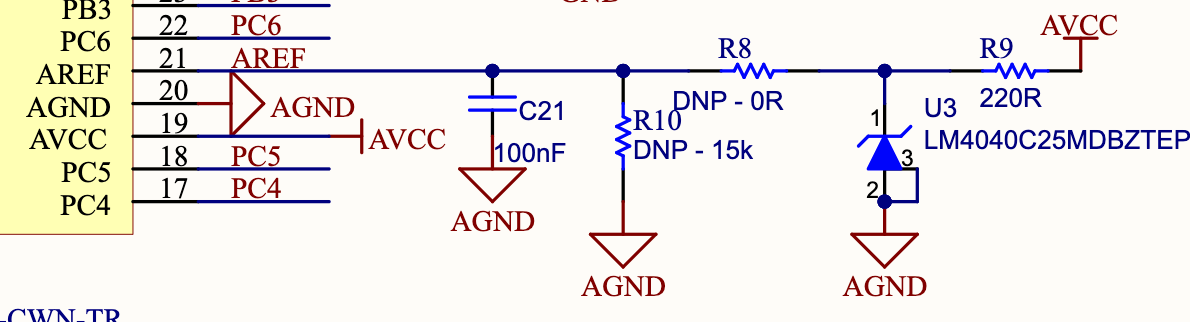
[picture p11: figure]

Figure 8: implementation of the internal ADC of the ATmega64

It can be seen that a separate VCC and GND ports are assigned with the internal ADC. Additionally, an external reference needs to be connected on the AREF pin. This external reference can be easily attained by using a component like the LM4040. Simply connect the anode to AVCC and the cathode to ground, and the component will automatically generate a reference voltage. R8 is there to allow the reference to be disconnected if necessary, and if it is not populated R10 should be placed to ground the AREF pin. C21 is the usual decoupling capacitor.

RTC

Depending on the complexity of the chosen MCU, an internal RTC may be available. It is generally not recommended to use for space applications simply because of the reliability issue. With that said, it can be used in pairs with an external clock and compared to mitigate the effect of clock drift.

## GPIOs

This section will glance over the different functionalities and features of MCU pins. This section will specifically look at different features that MCU pins can have and how they can be used for different designs.

Tri-State Logic

Tri-state logic, or three state logic, is a term often used when describing the functionality of a specific GPIO or set of GPIOs. It specifies that the GPIO has three possible states: high, low or high impedance. The high and low functionality are typical of an output pin, since it is able to drive the line high or low to control what it is connected to. The high impedance mode is the “input” mode. The fact that it is high impedance allows the pin to not interfere with the circuitry connected to it, but still allows it to sense a high or a low.

This brings a massive advantage for implementing complex digital design: signals that need to be controlled or be fed to the MCU can be connected to virtually any GPIO, since they can be set as inputs or outputs through software configuration. Only a few pins on an MCU are reserved for specific functions, which makes the overall integration much more simple. If an MCU does not specify tri state logic on a specific GPIO or set of GPIOs, these can not be set by software and will either be an input or an output, not both. This is important to look for since reversing the polarity of the input could lead to damage to the MCU.

Internal Peripherals Access

As complexity and size of MCUs increases, the number of features and internal peripherals will increase and can become very difficult to plan around if peripherals are only accessible through specific pins. To solve this issue, newer MCUs started offering internal peripheral access on virtually any GPIO, making the organization much easier and much more flexible. The chosen MCU obviously has to have that feature mentioned, but larger MCUs usually have this feature.

A great example of how this can be used is how the PIC16F15224T-I/MG is implemented on the EPS intro task (rev 4.0). The task requires the member to design a board around this very small MCU. One thing that the design requires is to have voltage sensing over a potentiometer and current sensing on the voltage line. The issue is that the PIC16F15224T-I/MG only has one internal ADC channel, so the members have to find a way around this issue. One of the solutions involves understanding internal peripheral access; the member can simply connect the current sense and voltage sense to two different GPIOs that have access to the internal ADC and simply read one at a time and switch the access to read the second value. This is much simpler than using an analog switch controlled by another GPIO.

Internal peripheral access also often allows different communication protocols to be accessed through different ports, which makes implementation with other components much easier.

## I/O Isolator

An I/O isolator is an isolation circuit that is used when connecting multiple MCU I/Os together. This is usually done when implementing redundant MCUs since they are required to communicate with each other, typically through UART ports and GPIOs to control reset and erase commands. Redundancy can only truly be achieved if both MCUs are isolated from each other’s faults. If two GPIOs or UART ports are directly connected together, a major failure from one MCU could destroy the second MCU. To avoid this, it is necessary to use the pin isolator shown in figure 9.

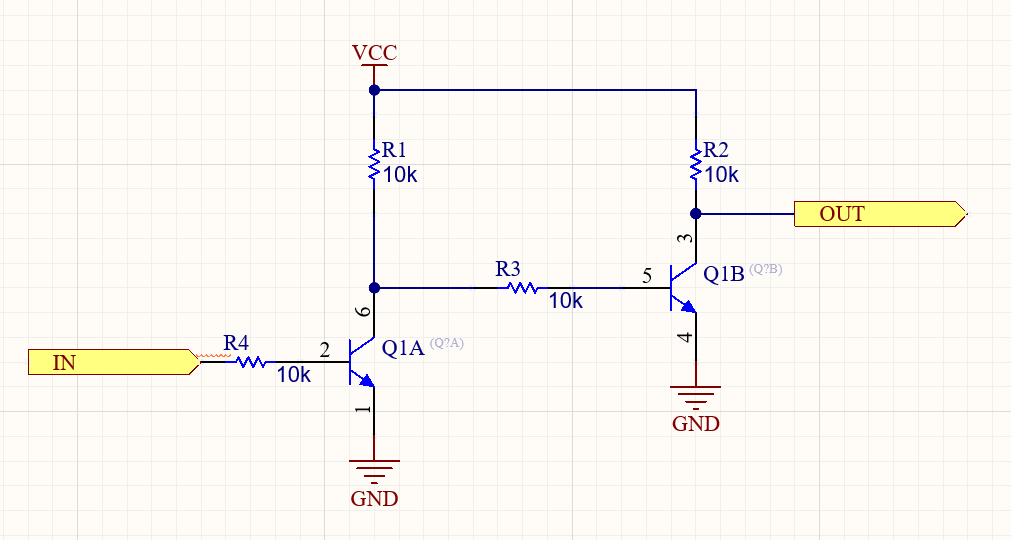
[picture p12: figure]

Figure 9: Pin Isolator Circuit

The way this circuit works is fairly simple. Instead of driving the output directly from the input, the input will bias or not Q1A, which will in term bias Q1B to the required output. If IN is low, Q1A is in the cutoff region, which allows Q1B to be directly biased by VCC. This directly connects OUT to ground, copying the low from IN to OUT. When IN goes high, Q1A is now in forward active mode, which effectively grounds the base of Q1B, putting it in cutoff mode. With Q1B in cutoff, OUT is directly connected to VCC and is therefore high.

One important consideration to take into account when using this pin isolator is that leaving the input floating will create an unknown state on the output. This is only an issue for important signals such as a RESET and ERASE control signal. Leaving them in an unknown state could trigger a RESET or ERASE even. To prevent this, pullup and pulldown resistors should be placed on the input of the isolator, not the output. Figure 10 shows how this was done on the CDH board of SC-ODIN, which serves as the interface between the two main flight computers. Note that they are used as sheet symbols in this implementation, but the circuit stays the same.

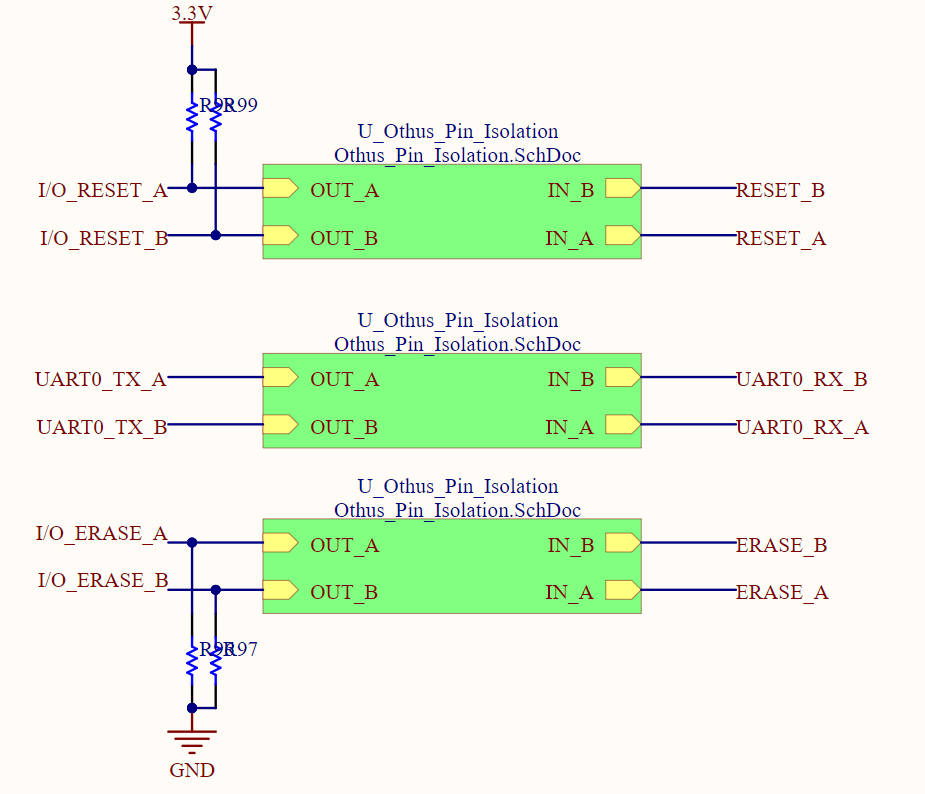
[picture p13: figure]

Figure 10: Pin Isolator with Pullup and Pulldown Resistors

## Debugging

MCU debugging is a crucial part of MCU Design since it allows for precise testing of the hardware implementation by the software team. Debugging is usually handled by a completely separate MCU whose sole purpose is to control the debug ports of the main MCU being tested. On breakout board designs, these debugging MCUs are integrated on the same PCB as the main MCU to allow simple and reliable connection between them. All that is required to do is to provide a connection to the debug MCU, and a connection to the main MCU. On final satellite PCB designs that integrate MCUs, the debug MCU should not be put on the PCB since it takes a lot of space that will not be used during normal operation of the satellite. For this reason, the debug ports of the MCUs should be broken out so an external debugger can connect and do the testing. This solution takes much less space on an already small PCB and will not leave unused hardware on the PCB. This section will look at both internal and external debugger implementations and general design rules surrounding both.

First, it is important to know what protocols are used for MCU debugging. There are two main protocols used, with each their own implementation. A third option is also available which integrates both on the same physical connections. The two main protocols are JTAG and SWD. Without going in depth into both, the main difference is the number of physical wires required for them. JTAG uses four to six while SWD uses two. Although it would make sense to use less cables, JTAG will be the preferred choice for SC-FREYR’s design because of the availability of the debugging chips and there is a lot of documentation available for this chip. The required pins are TCLK (clock), TDI (data input), TDO (data output) and TMS (test mode select). If the debugging is implemented externally, a mutual ground will need to be connected as well as a voltage reference pin.

Internal Debugger Implementation

The first implementation that will be shown in this section is the internal debugger implementation. This means that the debugging MCU will be on the same PCB as the main MCU it is trying to debug. A great example of this is the CDH breakout board developed for SC-FREYR. The main goal of this design is to make a breakout board that will allow the software team to test and debug the MCU chosen for the main flight computer. This will ease the development and testing process of the flight software and allow them to test out the interaction with a variety of peripherals. The debugging chip used on this design is the FT2232HL-Reel and the main MCU is the SAMV71Q21RT This section will look at the implementation of the debugging MCU as well as the connection between it and the main MCU. The main MCU’s implementation can be found in the sections above. The implementation of the FT2232HL-Reel can be seen in figure 11.

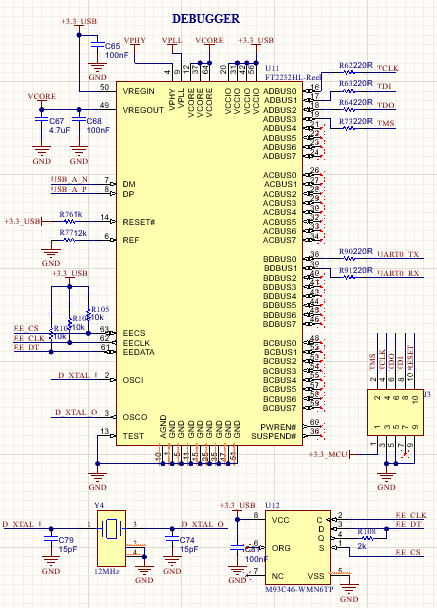
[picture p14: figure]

Figure 11: Implementation of the FT2232HL-Reel

This schematic obviously contains a lot of different parts, and this next subsection will look at each of them at a time. First, the power must be set properly. It is not as complicated as the power block of the SAMV71, but it is still crucial for it to be done correctly. Figure 12 shows the main decoupling and power filter components for the MCU, while figure 13 shows how to connect them.

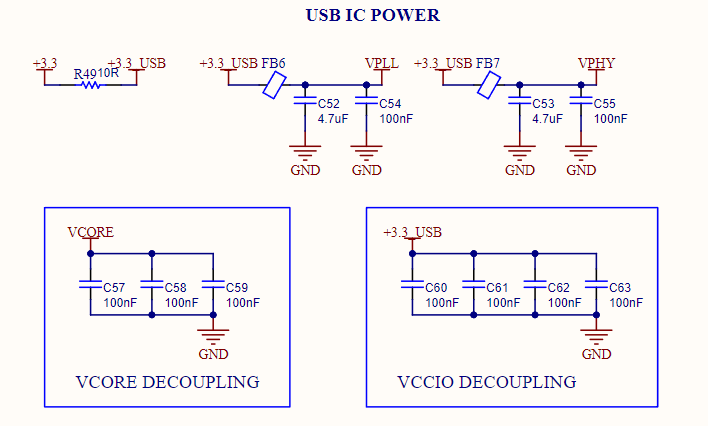
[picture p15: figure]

Figure 12: FT2232HL-Reel Decoupling Block

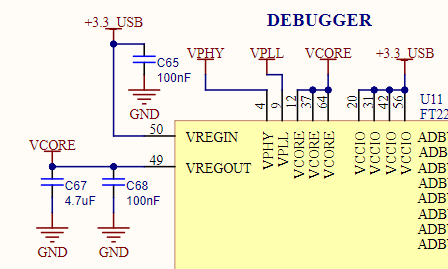
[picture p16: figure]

Figure 13: FT2232HL-Reel Power Connections

Most of the decoupling terminology is taken directly from the datasheet (page 51 of the datasheet (https://datasheet.ciiva.com/1787/ds-ft2232h-1787543.pdf?src-supplier=Digi-Key)). Since this breakout board will be used for testing purposes and not for space applications, using the internal voltage regulator makes the implementation much simpler and is used in this case. As always, ensure to have one 100nF capacitor per power pin, and use the standard ferrite bead instead of the suggested inductors.

Back to the implementation seen on figure 11, the whole point of this component is to provide MCU debugging through a simple USB port on the breakout board. For this reason, a USB connector should be implemented following the recommendation found in reference [7] page 18. The two USB nets should then be connected to the dedicated USB pins DM (data minus) and DP (data plus). The RESET# should be pulled up high through a 1K ohm since it won’t be necessary to reset the MCU. Per the datasheet instructions, REF should be grounded through a 12K ohm resistor and the three EE pins should be connected to an EEPROM per the datasheet (page 55 of datasheet (https://datasheet.ciiva.com/1787/ds-ft2232h-1787543.pdf?src-supplier=Digi-Key)). OSCI and OSCO are the typical crystal oscillator input and output pins that should be connected to a 12 MHz crystal with external capacitor on both pins. Lastly, TEST can simply be grounded and PWREN# and SUSPEND# can be left floating.

Now that the MCU is powered on and properly set up, the last step is to connect it to the main MCU using the correct connections. As mentioned earlier, the preferred debugging protocol that will be used through the course of SC-FREYR is JTAG. The four required connections can be seen at the top right of figure 11. TCLK is the clock line, TDI is the data input line, TDO is the data output line and TMS is the test mode select line. Since this implementation is done on the same PCB as the MCU it is trying to debug, there is no need for an additional ground line and an additional VREF line. One thing to note is the presence of UART ports. Although not necessary, it makes the communication between both MCU much simpler for our CDH team and should be connected unless space restrictions prevent it. The connections on the main MCU can be seen on figure 14.

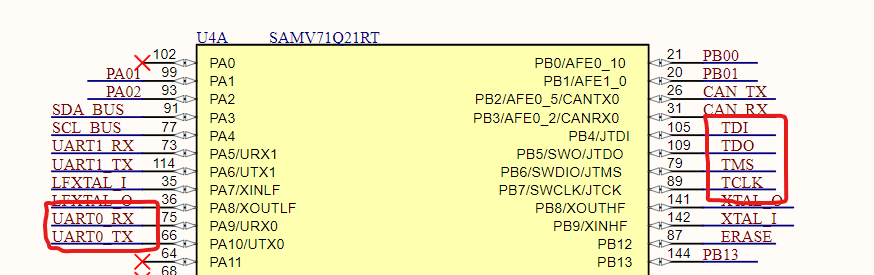
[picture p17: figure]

Figure 14: UART and JTAG Connections on the SAMV71

It is good design practice to break out the JTAG ports on a header to allow for external debugging in case the internal chip fails. This can be seen on figure 11 through the J3 connector.

External Debugger Implementation

The external debugger implementation is very similar to the internal implementation, with the difference that two different PCBs are required to be connected to each other. This section will not look at the design of the external debugger PCB since this will be thoroughly described and explained in the user manual for the MCU External Debugger design (SC-FREYR-EPS-709). Rather, this section will look at what needs to be broken out from the main MCU to allow the external debugger to connect to it. This will be valid for all EPS-100 designs that will integrate an MCU.

There are two common protocols used for debugging and running tests are JTAG and UART (see figure [7]). For UART, what needs to be broken out is pretty straight forward: the RX and TX lines with one ground. This can be seen in figure x. The fuse and ESD diodes are not required for flight components, only for ground equipment. It is also good to note that virtually any header or 3 pin connector will work for UART since they will then be manually wired using jumper wires. No specific connection layout is required.

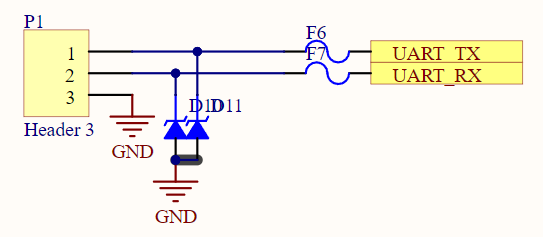
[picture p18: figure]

Figure x: UART Header Configuration

JTAG on the other hand requires a specific connector (or at least for Spacecraft equipment) and has a predefined pinout that needs to be followed across all systems to ensure compatibility. The connector used is the CNC Tech 3221-10-0100-00 or its right angle variant, the 3221-10-0200-00. In both cases, the pinout needs to follow the one shown in figure x. It is important to note that this connector is not bidirectional and will only fit in this specific direction.

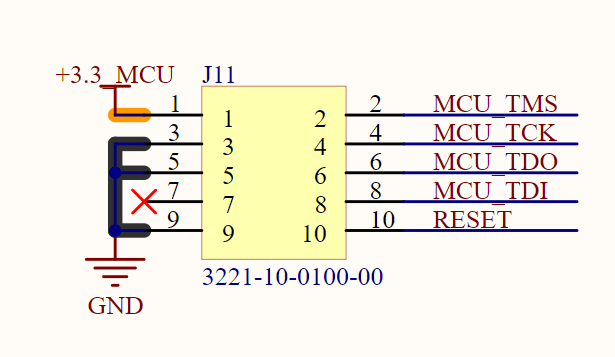
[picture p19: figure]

Figure x: JTAG Connector Pinout

Again, it is important to follow this exact pinout since the External Debugger (709 board) will interact with all the designs using this specific pinout.

## PCB Layout

Before beginning the PCB layout of an MCU, it is highly recommended to read the tutorial listed in reference [8] as it goes over a lot of very important concepts in PCB layout, some of which apply to MCU design. This section will mainly focus on the MCU specific design requirements and best practices.

The first thing that should be considered when laying out an MCU is the crystal. As mentioned before, it is the most critical part of MCU layout and needs to be kept as close as possible to the MCU, which is why it should be the first component to be placed. The only thing that needs to be considered before placing the crystal down is to ensure that its placement won’t interfere with important data lines such as USB and other high speed protocols. Figure x shows the placement of the two crystals required for the SC-FREYR 16-bit MCU.

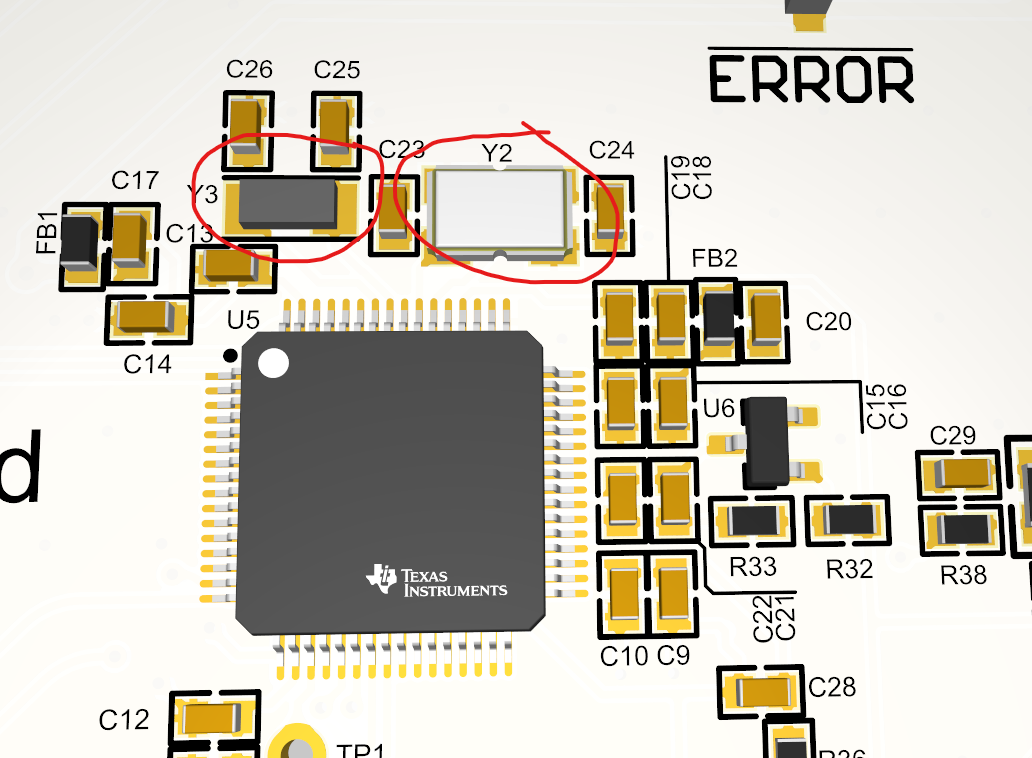
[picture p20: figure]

Figure x: Crystal placement on the MSP430FR5989IPMR

This layout ensures that the trace length between the crystals and the MCU is kept a minimum and that both load capacitors are as close as possible to the crystals themselves.

Crystals are very intricate components and require a lot more considerations than mentioned in this document if the goal is to implement them as well as possible. More in depth resources can be found under reference [9]

# Appendix A

There are multiple levels of accuracy to which these pi-filters can be designed to. Although it might not be necessary to go down all the way to extreme precision, the more accurate the design is the safer it will be.

The first step to ensure proper response of the pi-filter is to simulate it using LTspice, a free circuit simulation software commonly used. The first step will obviously be to download said software (download link (https://www.analog.com/en/design-center/design-tools-and-calculators/ltspice-simulator.html)).

CUBICS Project: SC-FREYR SCSD-LP-EPS-004-A

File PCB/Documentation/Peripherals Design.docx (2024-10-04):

SCSD-LP-EPS-002-B

# Peripherals Design


Prepared by

Gabriel Dubé

Electrical and Power System Lead

Jan 26, 2023

# Revision History

Date | Revision | Changes
1-Feb-2023 | A | Initial Release
-May-2023 | B | Added DACs, IOExpanders, Magnetometer, DSS and RADFET

# Table of Contents

Revision History 2

Table of Contents 3

References 4

Abbreviations and Definitions 5

Introduction 7

Peripherals 8

ADC 8

DAC 14

RTC 17

I/O Expanders 20

Transceivers 23

Flash Storage 24

Random Access Memory (RAM) 26

SD Card Reader 28

Magnetometer 29

Digital Sun Sensor 31

RADFET 32

Push Buttons 32

# References

[1] CUBICS - ELEC - Learning Resources - Learning Package [internal document on Google Drive], “Serial Communication”. Available from: https://docs.google.com/document/d/1fTaHIaRPVIfN-HuLPqiPyxERU_JW75ML_xxsHw8t4RE/edit?usp=sharing

[2] CUBICS - ELEC - Learning Resources - Learning Package [internal document on Google Drive], “MCU Design”. Available from: https://docs.google.com/document/d/1C6u4hayMrO_3dPMdv_w5Uh5XeICUirQNjUL7YavPuvA/edit?usp=share_link

[3] Arduino Documentation - Built-in example [website], “Debouncing on a Pushbutton”. Website link: https://docs.arduino.cc/built-in-examples/digital/Debounce

[4] CircuitMess Teaching/Learning Material [website], “Understanding the SD Card Slot”. Website link: https://community.circuitmess.com/t/understanding-the-sd-card-slot/2801

[5] CUBICS - ELEC - Learning Resources - Learning Package [internal document on Google Drive], “Power”. Available from: https://docs.google.com/document/d/1pKWWyXrTBQWnoESd13gtv7d2UHne3ekIcaZ94zOk2eo/edit?usp=sharing

[6] Texas Instruments [PDF, Datasheet], “TPS768xx-EP: Fast-Transient-Response 1-A Low-Dropout Voltage Regulators datasheet (Rev. B)”. Available at:

https://www.ti.com/lit/ds/symlink/tps76801-ep.pdf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

# Abbreviations and Definitions

Terminology | Definition
ADC | Analog to Digital Converter
ADCS | Attitude Determination and Control System
CAN | Controller Area Network
CDH | Command and Data Handling
CM | Common Mode
CSA | Canadian Space Agency
DM | Differential Mode
DNP | Do Not Place
ECU | Electrical Control Unit
ESD | Electrostatic Discharge
GPIO | General Purpose Input/Output
IC | Integrated Circuit
LDO | Low Drop-Out
LED | Light Emitting Diode
LVDS | Low-Voltage Differential Signaling
MCU | Micro Controller Unit
PDS | Power Distribution System
PSS | Power Supply System
RTC | Real Time Clock
SC-FREYR | Fermentation R- Extraterrestrial Yeast R-
SPEAR-M7 | Flight computer of SC-ODIN
SPI | Serial Peripheral Interface
TVS | Transient voltage suppressor
UART | Universal Asynchronous Receiver-Transmitter
UART | Universal Synchronous and Asynchronous Receiver-Transmitter
USB | Universal Serial Bus

# Introduction

Peripherals refer to all the external devices used in digital designs. Most of the time, these allow to implement functionalities that MCUs typically do not have integrated. Great examples are protocol transceiver, real time clocks, DRAM and much more. This document will do an overview of typical implementations of these peripheral devices, but it is important to keep in mind that these designs will change with specific ICs.

# Peripherals

## ADC

How does it work

Using an analog to digital converter is one of the easiest ways to implement different types of sensing, which makes this peripheral very relevant for designs that need to regulate themselves. Electrical systems that will operate in space need a lot of self regulating, so using ADCs in their design is important.

There are two main implementations of ADCs used in our CubeSat platform: MCU internal ADC and external ADC. As much as the first implementation sounds like the easiest and better way to do it, given most MCU have internal ADCs that can be used, for space application it is not always the better option. Digital chips are usually more sensitive to radiation, and relying on an MCU to both operate the system and do the self regulation is asking for a single point of failure. For this reason, external ADCs were widely used in SC-ODIN and will be used in SC-FREYR.

The idea behind an ADC is quite simple: it takes an analog voltage (ex: 1.2V, 2.7V, 500 mV, etc) and transforms it into digital data that can be transmitted to an MCU to read. This allows the MCU to sense voltage, current and even temperature (the specific implementation will be explained later). Another advantage of external ADCs is that analog voltages are very sensitive to noise, which means that if they are transmitted over a long distance, it will lose a lot of resolution and might be completely different from the intended sensing. On the other hand, digital data is much less affected by transmission distance and thus, the values will remain true to the intended reading.

This section will look at one particular IC that was used in ODIN: the ADC128S102CIMTX. It is a 12 bit ADC, which means it samples the voltage range from 0 to VA and divides it in 2^12 (8192) measurements. For a VA = 3.3V, this means that it can sense the analog voltage up to 0.8 mV precision. Without going into detail, it can be understood that a 0V reading will be translated to 0000 000 000, a 0.0008V reading will be translated to 0000 0000 0001 and so on. These strings of data are sent by serial communication to the MCU. The particular protocol used for this is defined by the chip, which means that during part selection, the chip can be chosen with its serial communication type in mind. In the case of the ADC128S102CIMTX, SPI is used and it will be required to implement proper device and bus protection (reference [1]).

Powering it

The first step in implementing the ADC chip is to properly power it. This should always be the first step in any design. It is especially important for ADCs in general because as mentioned earlier, analog voltages are very sensitive to noise and improperly powering the device will introduce a lot of noise. The way to ensure low interference is by splitting the analog and digital power. This can be seen on the chip’s schematic diagram.

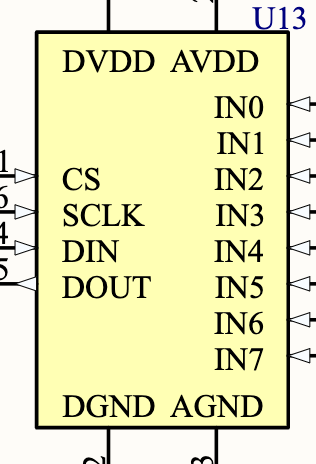
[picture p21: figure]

Figure 1: ADC128S102CIMTX schematic diagram

Two separate power rails are present: DVDD + DGND and AVDD + AGND. The A and D stand for analog and digital, respectively, and this allows the design to be separated. The digital power and ground can be connected to the main power and ground of the board and DVDD is required to run at 3.3V. The analog power, on the other hand, can be connected to the main power through much more filtering, usually using a ferrite bead and decoupling capacitors. The analog ground is the one that requires a bit more consideration: it can be directly connected to the main ground, but only at one singular point. The way to implement this on a schematic is using a net tie seen in Figure 2. It is also good practice to use net labels to separate VA and VD since you want to use VA as the analog reference.

Figure 2: Net Tie to Connect GND & AGND

This allows the two grounds to be connected directly together, but only in one point. (most often through a 10 mil track). The advantage of having a single connection point is that noise on the ground plane will not reach the analog ground as much. The PCB layout will be looked at in further detail at the end of this section. Lastly, both the analog and digital input require decoupling capacitors. The datasheet here recommends a 1uF and a 100nF on each input pin, but this might differ depending on the specific chip.

Channel connection

The second step is to connect the serial communication ports. To do this step, refer to reference [1]. It explains the implementation of SPI and its protection circuit. This specific chip has 8 channels for analog input, but this can vary depending on the chosen chip.

The next step is to properly implement the ADC inputs, i.e. IN0 through IN7 in Figure 1. The first thing to keep in mind is that the analog inputs cannot exceed the VA value. This means that if the VA input is at 3.3V, any higher voltage fed to the analog input will trigger internal protection and output wrong values. The second consideration regarding the analog input is that they need to be kept as clean and noise free as possible. To do so, the easiest way to filter most of the noise is to implement a low-pass filter on every analog input. The datasheet for the chosen ADC recommends a cutoff frequency of 40 KHz, but since we want to filter out as much noise as possible, and also use values commonly used across our designs, it is recommended to use a 1K ohm resistor with a 100nF capacitor. This gives us a cutoff frequency of 1.6 KHz, which should very effectively attenuate all AC noise.

This last section will look at three different ways to use the analog inputs to read voltage, current and even temperature. As mentioned before, all 3.3V references should be replaced by the net label assigned to VADD

Voltage sensing

This is the easiest one to implement, since all that is required is to feed the power input more or less directly into the analog inputs of the ADC. There are a few things to keep in mind: the input should never exceed VA as previously mentioned, so attempting to sense a 5V line with a VA of 3.3V could damage the inputs if not implemented properly. The simple solution to this is to create a voltage divider using high resistance to split the voltage. Two 100K ohm resistors is pretty standard for such a voltage divider. Lastly, it is important that the previously mentioned filter is implemented to protect the input, as the 1K resistor in line will not only enable the low pass filter to work, but also limit the current being fed from the power line.

Current sensing

Current sensing is the more tricky one to implement. The ideal current meter used in theoretical classes does not exist in reality, so another way to measure the current must be used. One option that comes to mind would be to put a resistance in the power line and measure the voltage drop across to calculate the current. Although this would work, it would also affect the power transfer of the line since getting a good voltage range implies a high resistance. To solve this, a low resistance should be used, typically in the range of 50 to 100 mOhm. These resistors are commonly called shunt resistors. With that said, another issue arises from this: the voltage drop across such a small resistance is very small, in the millivolts range or even less. Feeding this directly to the ADC inputs will not yield a high resolution which is less than optimal. This is why there is one more element to add to this: a current sense op-amp.

Current sense op-amps are operational amplifiers designed to serve as current sensors. The principle behind them is quite simple: it takes the voltage difference between its two inputs and amplifies it. This is perfect for current sensing since all is required is to connect the inputs across the low resistances and the small voltage drop generated will be greatly amplified, resulting in a much better resolution on the analog read. It is important to keep a Kelvin connection methodology around the small resistance, also called shunt resistance, which optimizes the analog read. Kelvin connection to a shunt can be seen in figure X.

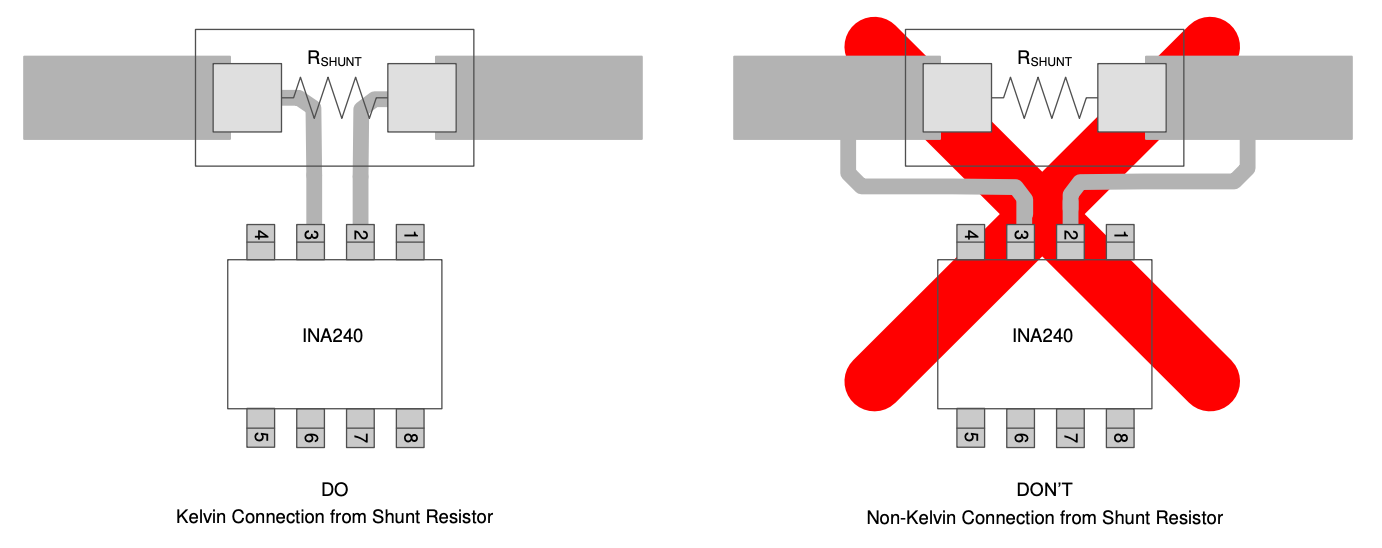
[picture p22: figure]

Figure X: Kelvin Connection to Shunt Resistor

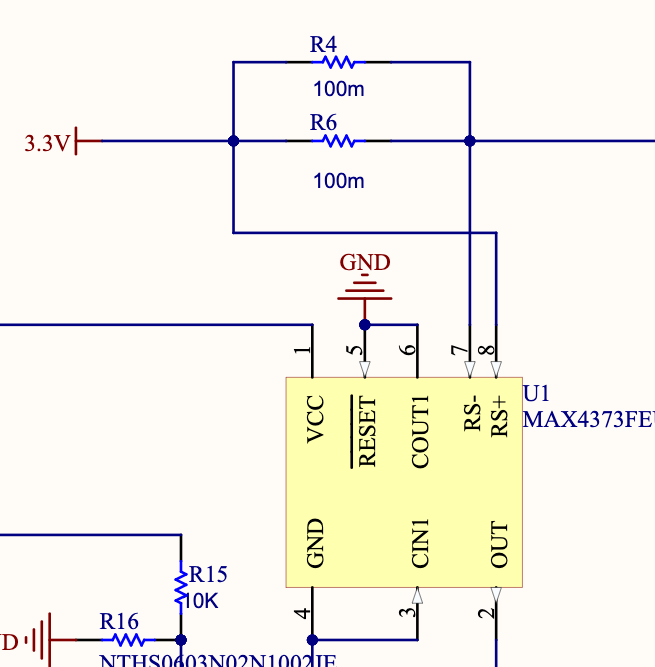
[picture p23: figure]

Figure 3: MAX4373 Current Sense Implementation

There are a few things to note on Figure 3. First, two 100 mOhm resistors were used to equate a 50 mOhm resistance. The reason for this is because this particular 3.3 power line has a typical current consumption of 1 to 1.2 amps. All this current shoved into a single resistor would result in a lot of heat generated, which could end up reaching above the rated temperature and damage the component. Instead, two resistors are used to split the power dissipation in two. Another thing to notice is that this is a unidirectional current sense amplifier, which means that RS+ must always be higher than RS-. Bidirectional op-amps are available but are usually more costly and unnecessary for most designs. Lastly, the gain of the op-amp is the most important parameter to consider when doing part selection. It needs to be chosen to provide an optimal voltage range on the output, increasing the resolution of the ADC. It is also good to note that since the output current of the op-amp is negligible, it is not necessary to take into account the voltage drop across the filtering resistor.

The math behind this is not particularly complicated, but it still needs to be understood. First, the voltage and maximum current consumption of the line needs to be known. In the case of Figure 3, the maximum consumption is 1 to 1.2 Amps. This is calculated by adding the maximum power consumption of each device on the line. Then, the voltage drop across the shunt resistor needs to be calculated. Since V = IR, it can easily be determined that the maximum voltage drop across the shunt resistor is 60 mV. Now, the goal will be to amplify this voltage to utilize as much of the available voltage range of the ADC as possible. Since the ADCs in our design use 3.3V as the VA, the op-amp needs to have a gain that would get it close to this. The MAX4373 has different variants, with the one in Figure 3 having a 50 V/V gain. This is perfect since 60 mV * 50 V/V yields 3V on the output. Although it does not quite reach the full 3.3 range, it is more than acceptable given the high resolution obtained from this.

The last step to this lengthy current sensing implementation is to inform the software team of the math behind the design. In the case of Figure 3, with the op-amp gain at 50, and the shunt resistance at 50 mOhm, the following equation can be derived to obtain the current from the read voltage:

Current = (AnalogRead)/(Op-Amp Gain)× 1/(Shunt Resistance)

Current (for shown design) = (AnalogRead)/(50 V/V)× 1/0.05

From this equation, any current can be determined by reading the analog voltage on the chosen input. The values of the gain and the shunt resistance should be adjusted to obtain the best resolution possible, which means the output voltage of the op-amp should be as close as possible to VA.

Temperature sensing

Temperature sensing is also pretty straightforward to implement. It only requires one particular component: a thermistor. Without going deep into the physics of this component, it is simply a resistor that has a variable resistance based on temperature. They have a base value at 25°C, usually 10K, and a temperature coefficient that determines the change in resistance with the change in temperature. The only challenge with this component is to figure out how to read this change and turn it into temperature sensing. It turns out to also be very straightforward: form a voltage divider using a thermistor and a regular 10K, and read the divided voltage. When the thermistor’s resistance changes, the ratio between it and the 10K resistor also does, resulting in a change of voltage on the divider.

Figure 4: Typical Implementation of a Thermistor

RT is the designator used for thermistors. THERM2 simply reads from the divider and the temperature can be determined from that reading. The math behind extracting the temperature from the voltage reading will have to be determined using the temperature coefficient of the chosen thermistor, which can be found in the data sheet. Note: The 100 nF capacitor is only there for filtering purposes.

Here is an example of the math behind determining temperature based on the voltage input from THERM2. Va is the reference voltage and RTcoefficient can be determined from the data sheet of the specific thermistor used.

Temp = 25 + ((100-((V_(input) *100)/(V_a -V_(input))))/(RT_(coefficient)))C

Temp = 25 + ((100-((V_(input) *100)/(3.3-V_(input))))/3.9)C

Figure 5 shows the final implementation of the ADC. Note that ISENSE stands for current sense, and THERM stands for thermal sensing.

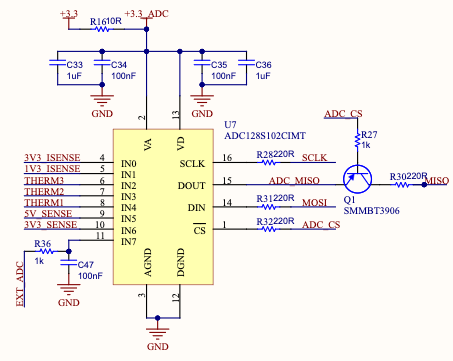
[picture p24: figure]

Figure 5: ADC Implementation

## DAC

Digital to analog converter, or DAC, is the exact opposite of an ADC. It takes a digital signal as input and outputs an analog voltage. This can be used to control specific circuitry that depends on an analog voltage to modulate its functions. The digital data can be transferred via virtually any protocol as long as the selected chip supports it, and the DAC will convert it to an analog signal with a precision based on the chip itself. Much like the ADC, it will have a precision rating, for example 10 bit, which means it can adjust the analog output up to Vref/2^10 precision. They also have a certain amount of channels available depending on the specific chosen IC.

This document will use a simple example of a DAC implemented on the power supply system of SC-ODIN. DACs are very specific to certain implementations, so this is the only time it was used for previous projects. With that said, it is still good to understand how it works and how it can be used for complex designs. The specific chip used on the PSS is the DAC121S101CIMK/NOPB. It is a 12-bit, automotive grade, SPI compatible digital to analog converter. More precisely, it uses a modified version of SPI since DACs do not need to transmit any data on the MISO bus. They simply need to receive the digital signal that needs to be converted as well as the clock signal. The schematic diagram of the DAC121S can be seen in figure 6.

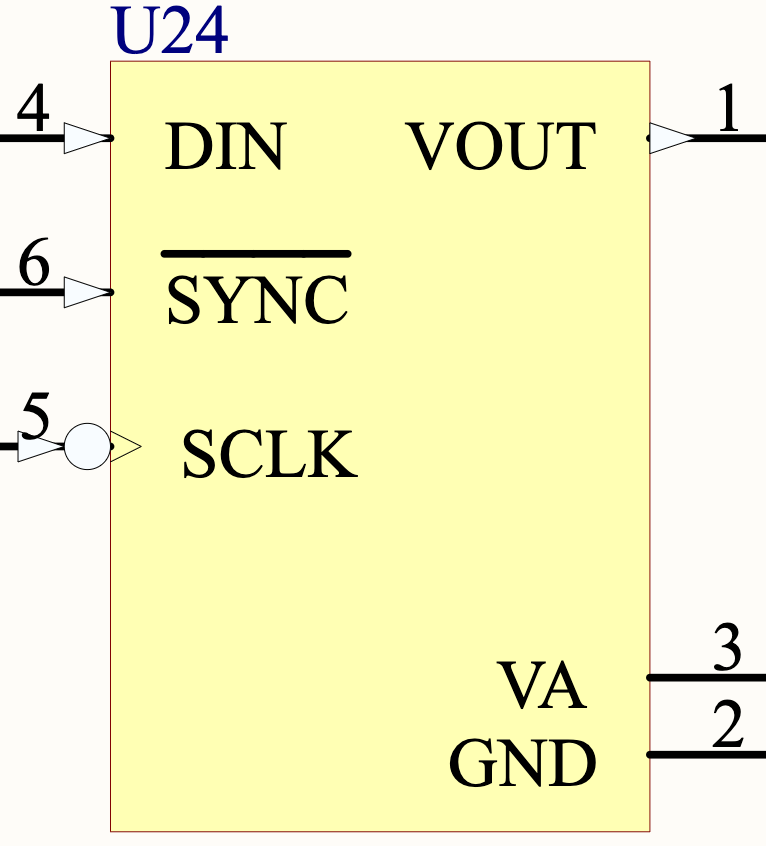
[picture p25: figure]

Figure 6: Schematic Diagram of the DAC121S101CIMK/NOPB

Firstly, the power ports of the devices are VA and GND. VA serves as both the power supply and reference voltage for the DAC, and should ideally be connected to a stable voltage reference that is able to supply current. DIN is the usual slave data input of the SPI bus, which means it needs to be connected to MOSI. SCLK can simply be connected to the SPI clock and VOUT is the output of the DAC, meaning it will be an analog voltage and needs to be kept as clean as possible. Finally, the SYNC pin is associated with the previously mentioned alternative SPI implementation for DACs. It serves mainly as the usual Chip Select of the SPI protocol, but it also has an interrupt functionality depending on the timing of the signal. This should simply be connected to an MCU pin and the software team will be responsible for specific interrupt implementation. Figure 7 shows the overall implementation of the DAC.

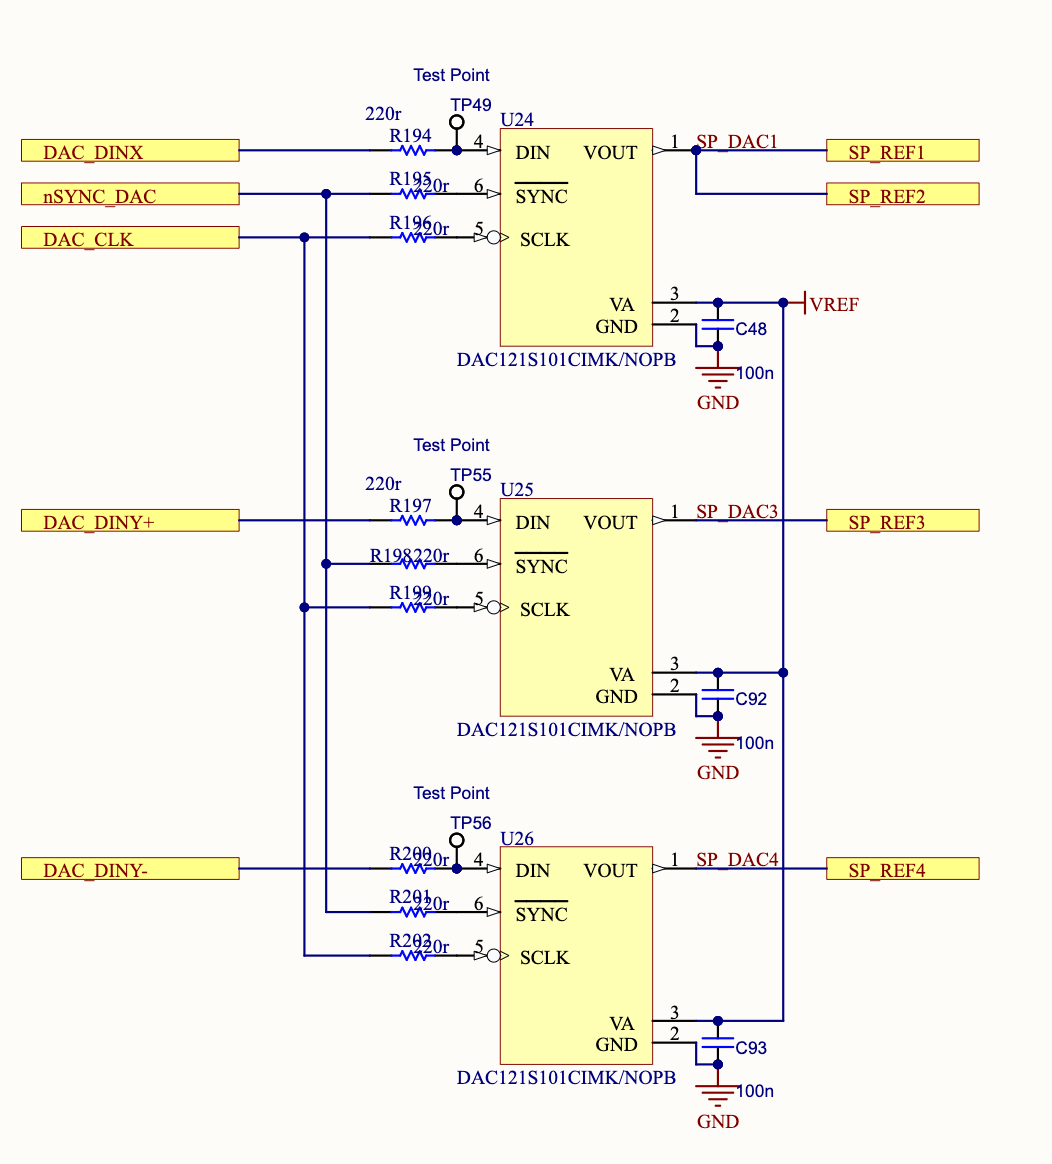
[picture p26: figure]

Figure 7: Implementation of the DAC121S101CIMK/NOPB

In this implementation, all SYNC pins are connected together to reduce the number of chip select pins required and it does not bring any concern for collisions on the MISO bus given they do not output anything. All the references are individually controlled using different data input lines, which is also another feature of this particular SPI implementation.

The implementation of this DAC on the PSS was done to control the shunt regulators. Shunt regulators are a set of circuitry that is able to dissipate a large amount of current if the system input is too high for its power consumption. They are particularly important when dealing with solar panels since they supply power regardless of the state of the system. Without going in depth on the circuitry, the role of the DAC is to adjust a voltage reference to an op-amp, which will in turn adjust the amount of current that is shunted out from the power input. Figure 8 shows a broad overview of the shunt regulator implementation, with SP_REF behind the reference voltage fully controlled by the DACs.


Figure 8: Shunt Regulator Circuit (first half only)

The basic principle of operation of this circuit is that a voltage monitor from the solar panels is fed into the negative terminal of an op-amp and the positive terminal is connected to the DAC voltage reference. The solar panel voltage monitor is constantly read by the MCU and if the power input becomes excessive compared to the need of the system, the MCU will control the DAC reference, which will generate a precise output voltage from the op-amp and this will be fed to the gate of a power MOSFET. Depending on the applied bias from the op-amp, the power MOSFET will dissipate a precise amount of power from the solar panel input.

## RTC

A real time clock does exactly what you would expect it to do: it keeps track of the time. Although it sounds like it would be an irrelevant component since time is available on any electronic devices now, it is actually necessary on satellites that will not be in contact with earth at all time. Time tracking is not as simple as one might think, and this is why RTCs are really important for any electrical systems like the ones we produce. It is particularly relevant for MCU designs, as is discussed in the Learning Package on MCU design (reference [2]).

The way an RTC works is quite interesting. The principle behind it is the exact same as a quartz watch that people wear everyday: it utilizes a quartz crystal. Crystals, also known as oscillators, are actual physical crystals that possess particular properties crucial to accurate time keeping. Basically, when a very small electrical signal is sent through a crystal, it will start to oscillate at a very precise frequency. For time counting, the frequency of the crystal needs to be precisely 32.768 KHz. The reason for this is quite interesting: it is the exact frequency that results in a 1 Hz signal when 15 flip-flops are connected in an array. Without going into depth, feeding a clock signal through a flip-flop will make it output a clock signal with half the frequency of the input. Chain this reaction 15 times with a 32.768 KHz input clock will result in a 1 Hz signal at the output. In other words, 2^15 = 32 768. This is how time is measured, since counting a 1 Hz signal is very simple and crystals are very precise so it can be relied upon to keep accurate track of time.

This section will look at a particular RTC: the PCA85063A. It is a pretty straightforward component to implement and includes all the features required from an RTC. Figure 9 shows the schematic diagram of this IC.

Figure 9: Schematic Diagram of the PCA85063A

The diagram for most RTCs will have similar pin layouts: VDD and VSS for power, OSCI and OSCO for the crystal connections and a few connections for data depending on the protocol used by the chip. This particular chip uses I2C, and has an interrupt pin as well as a CLKOUT pin. This is because it has two extra features: a clock divider and an alarm. This will be explained at the end of this section, for now the main features will be looked at.

First, the RTC needs to be properly powered. Fortunately, it does not require any special filtering on the power inputs or ground node considerations. Simply add the usual 100 nF capacitor between the VDD pin and GND. The one thing that is unique to an RTC is that it needs to be powered on all the time, otherwise it will lose track of the time, just like old alarm clocks. To counter this, a simple coin cell battery can be small. RTCs usually consume very little power, so a simple coin cell will last for a very long time. With this particular IC, a CR2032 will last multiple years so there is no need for a big battery. Coin cell batteries also often supply the correct voltage level, in this case 3V, which is really easy to implement.

Second, it is important to understand how to properly connect the crystal. Any mistakes in implementation could result in massive errors and incorrect time keeping. For most RTCs, including the PCA85063, the required crystal is a quartz 32.768 KHz crystal. They come in different formats and precision, but in general most crystals with these characteristics will do. The chosen one for this design is the Q0.032768-JTX310-12.5-10-T1-HMR-LF (crystals usually have very weird names). Figure 10 shows the proper way to connect the crystal.

Figure 10: Crystal Connection to the RTC

Few things to note on this figure: crystals are usually bidirectional, so there is no specific way to connect the in and out ports of the RTC. The second thing is the presence of capacitors. Unlike one would think at first, these are not decoupling capacitors. The physics behind them is complicated, so all that is really required to know is that they need to be on both sides of the crystal and have a value of 12 pF for 32.768 KHz crystals. PCB layout rules are more complicated when it comes to crystals, but this subject will be talked about in depth in another Learning Package.

Third thing to implement is the data lines. This particular chip uses I2C and will require the usual protection circuit for this protocol. Refer to reference [1] for further details on I2C and its protector. The used protocol will differ depending on the selected IC.

Lastly, this chip has two extra features: the clock divider and the alarm clock. The clock divider is a feature that allows you to output a clock signal that is either exactly 32.768 KHz in frequency, or any fraction of that. This can be useful if other parts of the design require a specific clock signal. Most of the time, it is simply fed to the MCU for it to use. The alarm clock feature is implemented using an interrupt pin that can simply be connected to the main MCU. It is also good to know that the interrupt can be used in pairs with the clock signal for specific applications.


Figure 11: Implementation of the PCA85063

A concern that arises from any crystal based component like RTCs is clock drift. Although crystals are generally very precise, external environmental factors can affect their accuracy and introduce small errors. These errors can not only lead to timekeeping issues, but can also cause imprecisions in the system. A great example of this is the ADCS model implemented on ODIN. The model controls the orientation of the satellite during orbit and hence, controls the pointing accuracy of the antenna to the ground station. The estimated angle error from SC-ODIN’s model is 2.22 degrees, with 0.95 of that due to clock drift alone. This shows that clock drift is very much a concern and needs to be addressed. In space, the environmental factors that increase clock drift are all the more present, and corrections need to be put in place. This next section will look at different methods to reduce clock drift error.

The first method is to compare multiple available clock signals and calculate the drift based on the other clock signals. Once the drift becomes significant, it is possible to reset a clock signal and synchronize it to the rest of the system. This method does not require any outside interaction to correct itself, but it will also eventually have the entire system out of phase with “earth’s time”. The second method addresses this issue, but it requires communication from the ground station to the satellite. It is possible to send a synchronization signal which would adjust all the clocks onboard the satellite to the earth’s clock, thus removing all drift introduced between two communication windows.

## I/O Expanders

I/O expanders are very useful peripheral devices when designing big systems that need to be controlled by an MCU. One of the main issues that occurs with dense and complex designs is that a lot of I/Os are required to control every part of the design, and MCUs have limited ports that can be used. This is especially true when dealing with smaller size MCUs since they have a small amount of pins, with a big majority reserved for power, crystals and communication protocols. The I/O expander, as the name suggests, solves this problem by providing multiple I/O ports that are controlled through a communication protocol. Depending on the specific device, some offer two or three state logic, allowing the I/O expander to not only output control signals but also read statuses and flags.

I/O expanders were used a lot during SC-ODIN, more specifically on both the power board (PSS and PDS). Since they are both mainly analog or TTL based designs, they require a lot of monitoring and regulation that digital designs usually integrate using communication protocols. This does not work for analog designs since they require specific control signals to be applied to different sections of the design. This is why I/O expanders are so useful: they allow a digital bus to control multiple aspects of a design and read the provided statuses. This section will look at the I/O expander implemented on the PSS, the PCA9539APW,118, to concretely see how they can be used to control complex analog circuits.

The PCA9539APW,118 uses I2C as its communication protocol, three state logic on all 16 pins and interrupt/reset ports. Figure 12 shows the schematic footprint of the component. The interrupt and reset pin can be seen as well as the I2C ports and the address controls.


Figure 12: Schematic Footprint of the PCA9539APW,118

On SC-ODIN, the PSS is almost fully analog given the reliability of analog circuits for space applications. The issue with analog circuits is that they are bulky, power hungry and require a lot of control signals. In this particular implementation, the I/O expander controlled all heater enables, all shunt regulator enables and the charger resets. It was also responsible for reading the fault signals from the undervoltage, overvoltage and short circuit protections. The full circuit implementation can be seen in figure 13.


Figure 13: Implementation of the PCA9539APW,118

There are a few things to note on this implementation. The I2C bus implementation is very standard, with the added feature that the A0 and A1 pins can be used to change the slave address of the device on the bus. Usually, an address is chosen by CDH for each slave device and all that is required is to tie A0 and A1 to ground or VDD using 10K resistors to set the address. For this implementation, they were connected to I/Os of the main computer so the final decision on the address could be done after implementation. It is important to note that it is not good practice, and all the addresses should be planned out in advance. The proper way to set up I2C address selectors can actually be seen on figure x, which is how the magnetometer address selection was set. In comparison with the implementation of the I/O expander, it simply requires two extra resistors that will be left DNP instead of using 2 full I/Os on a microcontroller. This is also much more robust as a bug with an MCU can cause the device to change address and create issues on the I2C bus.


Figure 14: Correct Implementation of the I2C Address Selector

R15, R16 are used to tie the address pins to 3.3V and R25, R26 are used to tie the address pins to GND. To select the address, simply leave 2 of the resistors DNP to write the address in binary.

Another important thing to note on figure x is the pull up resistors present on both the RST and INT given they are both active low. They both need to be connected to I/Os of the controlling MCU of the design to allow CDH to control the device appropriately. Finally, it is important to put proper I/O protection on each pin to ensure that the control signals don’t damage the component. In general, a simple 1K resistor is required for all the I/Os that will be implemented as outputs (like P0_3 to P0_7 and P1_3 to P1_7 on figure x) and a higher resistance, usually above 100K for I/Os that will be used as inputs (P0_1, P0_2, P1_1 & P1_2 on figure x). It is also important to add pullup or pulldown resistors on input channels depending on the polarity of the status signal.

## Transceivers

Before beginning this section, it is highly recommended to know at least the basics of serial communication (reference [1] for the basics). Transceivers are devices that use a certain type of data and transmit it in a different way depending on the requirement of the design. For example, some transceivers can take a certain protocol as input and transmit using another protocol. This is particularly relevant considering different protocols can transmit over different lengths, and a transceiver allows a design to transmit over the limitation for length of a particular protocol. Some are also able to transform common mode signals into differential mode signals, which are usually more resilient to noise and can transmit over greater distances.

One of the most commonly used transceivers is a CAN bus transceiver. The reason for this is quite simple: a lot of MCUs will not have an integrated transceiver, but rather a CAN_RX and CAN_TX line. To solve this problem, a CAN transceiver is used. This can be seen in the CAN Bus section of reference [1].

This illustrates the main function of transceivers: take a certain type of data as input, often from protocols like UART and RS232, and transform them into differential signals like CAN, LVDS, RS485 and more. Another example of this is the MAX3488. This chip, depending on the package used, is able to communicate from RS232 to RS422 with controlled slew rate for EMI reduction, driver protection and increased line length. Figure 15 shows the implementation of this chip to allow an MCU to transmit to the main imager of the satellite. The MCU in question did not feature RS422 communication, so the transceiver was used to convert one of its UART ports (which is very similar to RS232) to the required RS422 protocol.


Figure 15: Implementation of the MAX3488

The nice thing about transceivers is that they are generally very easy to implement: connect it to power, connect the input protocol and connect the output protocol. The only thing to consider is that some protocols will require bus terminations, hence the presence of R20 and R21. These will either need to be matched to the overall bus impedance, or put to a high resistance if no significant power transfer is required.
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

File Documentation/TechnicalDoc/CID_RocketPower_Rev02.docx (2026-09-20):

Control Interface Document

RocketPower Avionics System

Document ID: CID-RocketPower-Avionics
Prepared by: Anas Senouci
Project: RocketPower Flight Computer

Revision History

Revision | Date | Description
Rev 00 | 2025-12-28 | Initial skeleton, not yet checked against schematics/firmware.
Rev 01 | 2026-08-09 | Verified against PCB/main schematics and FlightComputer/src. Added command/telemetry packet spec (5.5), actuation interfaces (6), backup-deployment safety path (8.4), GPIO appendix. Corrected: SD is SDIO not SPI (5.3); pyro path has an intentional 7ohm current-limit resistor (7.3); radio is LoRa E22-900T22D, not the legacy XBee reference (5.1).
Rev 02 | 2026-08-10 | Added Section 13 (mass/CG/CP tracking). Trimmed document-wide for length.

# Abstract

Defines the control, electrical, and logical interfaces of the RocketPower avionics system -- a custom flight computer (bare NXP MIMXRT1062, Teensy 4.1-compatible), its ground station, and the KiCad PCB connecting them to sensors, radio, pyro channels, and actuated fins -- so the system can be understood, verified, or reproduced without reading firmware/schematic source directly.

# 1. Introduction

## 1.1 Purpose

Defines all control interfaces of the RocketPower avionics system: logical control signals, power interfaces, communication protocols, actuation interfaces, and pyrotechnic initiation interfaces.

## 1.2 Scope

- Electrical power interfaces
- Sensor interfaces
- Communication interfaces, including the full ground<->flight binary packet protocol
- Actuation interfaces (fins, camera, status indicators)
- Pyrotechnic channel control interfaces
- Safety and arming interfaces
- Flight state machine behavior as it affects control interfaces

Mechanical design and firmware internals not tied to control behavior are out of scope.

## 1.3 Definitions and Acronyms

Term | Definition
CID | Control Interface Document
MCU | Microcontroller Unit (NXP MIMXRT1062)
FC | Flight Computer
GCS | Ground Control Station
IMU | Inertial Measurement Unit
GPIO | General Purpose Input/Output
PWM | Pulse-Width Modulation
I2C | Inter-Integrated Circuit bus
SDIO | Native 4-bit microSD bus
UART | Serial link
RSSI | Received Signal Strength Indicator
PYRO | Pyrotechnic output channel
+BATT | Raw battery rail, upstream of the main fuse
+7.5V | Fused, monitored, unregulated rail feeding pyro and servos
RBF | Remove-Before-Flight hardware link
LoRa | Modulation used by the E22-900T22D telemetry radio

# 2. System Overview

## 2.1 System Description

The RocketPower flight computer handles: sensor acquisition, flight-state estimation, SD logging, ground telemetry/commands, pyrotechnic control, and optional closed-loop fin actuation. Powered by a 2S LiPo (7.4 V nominal).

## 2.2 High-Level Architecture

Bare NXP MIMXRT1062DVL6B (Teensy 4.1 silicon) on a custom PCB, with an MKL02Z32VFG4 coprocessor for USB/bootloader, flashed via PlatformIO/Teensy toolchain.

- Power: +BATT -> fuse -> INA260 shunt -> TPS62111RSAR buck (3.3V) + unregulated +7.5V (pyro/servos)
- Sensing: 5 I2C sensors across 3 buses (Section 4)
- Storage: microSD over native SDIO (5.3)
- Comms: LoRa UART telemetry link, UART camera link, USB-C (5)
- Actuation: 3 pyro channels, 4 fin servos (6-7)
- Indication: 4 status LEDs + 2 hardwired indicators (6.3)
- Safety: hardware RBF link, software arm/disarm, independent backup-deployment monitor (8)

State | Meaning
IDLE | Powered on, waiting for ARM
ARMED | Pyro armed; liftoff detection active
POWERED_ASCENT | Motor burning
COAST | Burned out, coasting to apogee
APOGEE | Apogee confirmed; CH2 fires
DESCENT | Descending under chute
LANDED | Altitude stable; flight over

# 3. Power Interfaces
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

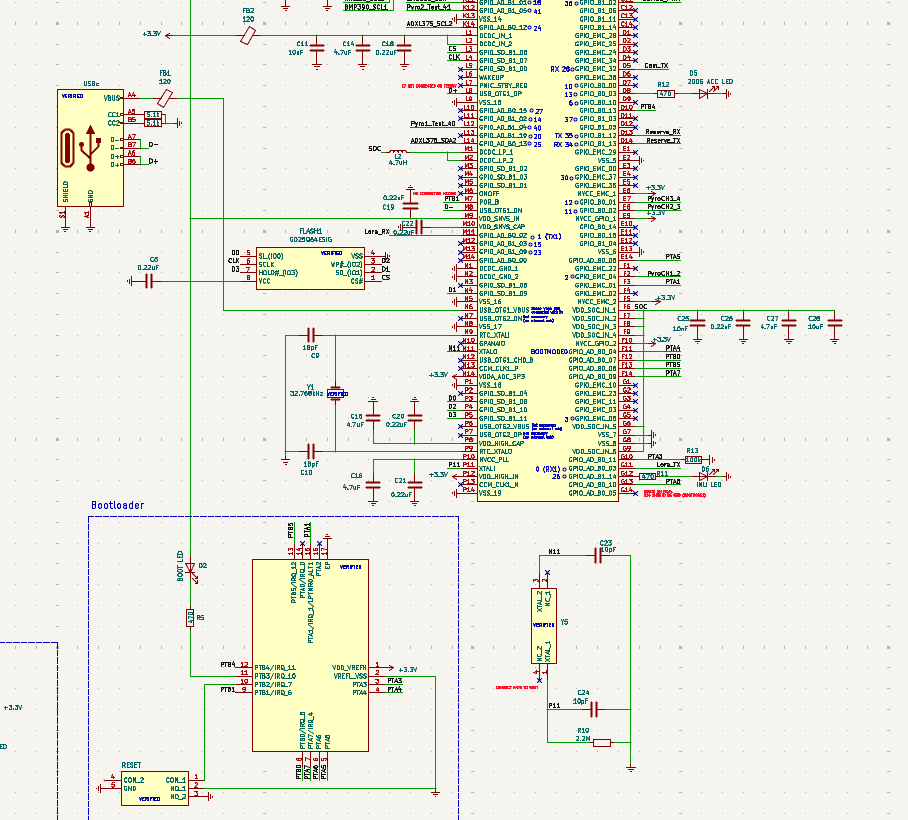
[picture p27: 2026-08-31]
Media/LinkedIn_Post1/PCBSchematic.png

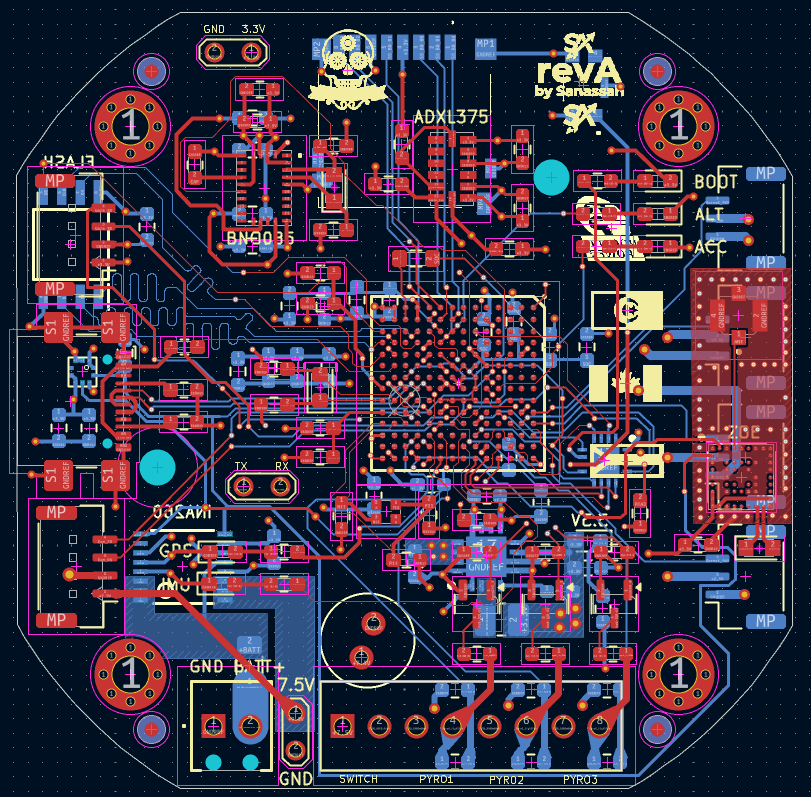
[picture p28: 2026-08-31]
Media/LinkedIn_Post1/PCBLAYOUT.png

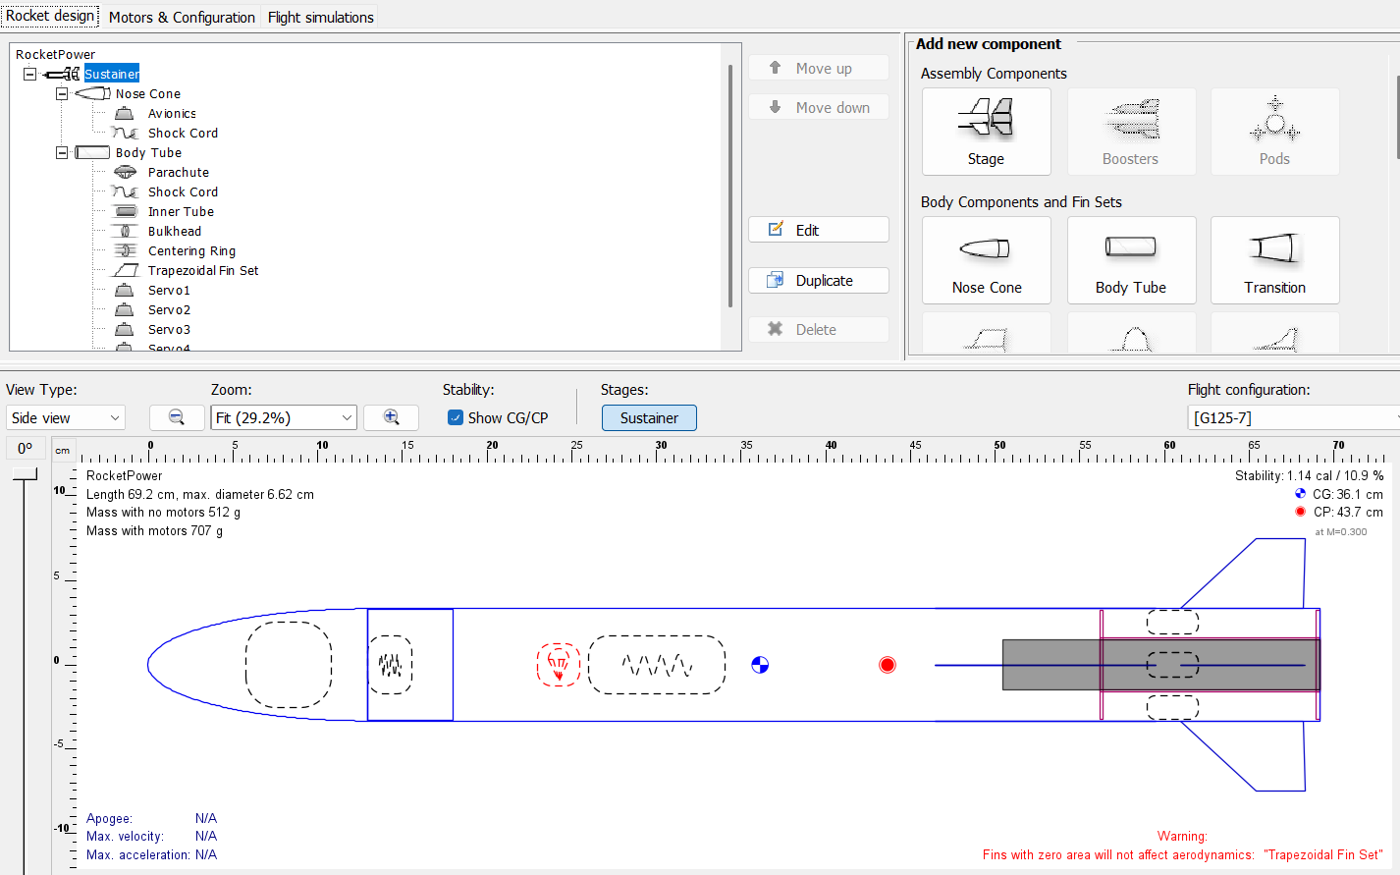
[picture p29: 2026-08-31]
Media/LinkedIn_Post1/OpenRocket.png

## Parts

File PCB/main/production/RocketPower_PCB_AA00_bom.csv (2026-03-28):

Designator | Footprint | Quantity | Value | LCSC Part #
ADXL375 | ADXL375BCCZRL | 1 | ACC | C579466
APS6404L-SQH-SN1 | APS6404L | 1 | PSRAM | C7466603
BMP1 | BMP388 | 1 | ALTIMETER | C2684802
BNO085 | BNO085 | 1 | IMU | C5189642
C1, C11, C28 | 0603 | 3 | 10uF | C70225
C10, C9 | 0603 | 2 | 18pF | C1647
C12, C13, C17, C18, C19, C20, C21, C22, C26, C4, C5 | 0603 | 11 | 0.22uF | C106216
C14, C15, C16, C27, C38, C8 | 0603 | 6 | 4.7uF | C19666
C2 | 0603 | 1 | 22uF | C2762594
C23, C24 | 0603 | 2 | 10pF | C2168929
C25, C7 | 0603 | 2 | 10nF | C149619
C29, C30, C31, C34, C35, C37, C39 | 0603 | 7 | 0.1uF | C48579250
C3, C36, C40 | 0603 | 3 | 1uF | C1592
C32, C33 | 0603 | 2 | 22pF | C49326308
C41 | C_Radial_D6.3mm_H11.0mm_P2.50mm | 1 | 470uf | C1020067
C6 | 0603 | 1 | 2.2uF | C23630
CONMHF1-SMD-G-T1 | CONMHF1SMDGT | 1 | ANTENNA | C22442695
D1 | 0603 | 1 | 3.3V LED | C20433785
D2 | 0603 | 1 | BOOT LED | C20433785
D3 | 0603 | 1 | GPS LED | C20433785
D4 | 0603 | 1 | Altimeter LED | C20433785
D5 | 0603 | 1 | 200G ACC LED | C20433785
D6 | 0603 | 1 | IMU LED | C20433785
D7 | ESD9R3_3ST5G | 1 | ESD9R3.3ST5G | C233388
DM3D-SF1 | DM3DSF | 1 | MicroSD | C719027
F1 | 1206 | 1 | 6A | C183157
FB1, FB2 | 0603 | 2 | 120 | C14709
INA260 | TSSOP16 | 1 | INA260 | C2155885
KMR241GLFS1 | KMR421GULCLFS | 1 | RESET | C221682
L1 | 1008 | 1 | 6.8uH | C307868
L2 | 0805 | 1 | 4.7uH | C397305
L3 | 0805 | 1 | 2.2μH | C83998
MIMXRT1062DVL6B1 | BGA196C80P14X14_1200X1200X152 | 1 | MCU | C2847497
Q1, Q2, Q3 | SOT-23 | 3 | SI2302 | C460978
R1, R2 | 0603 | 2 | 5.1k | C1647
R10 | 0603 | 1 | 2.2M | C18679
R11, R12, R5, R7, R9 | 0603 | 5 | 470 | C23179
R13 | 0603 | 1 | 100k | C14675
R14, R15, R16, R6, R8 | 0603 | 5 | 4.7k | C23162
R17, R18, R19, R20, R23, R24, R27, R28, R31 | 0603 | 9 | 10k | C25804
R21, R25, R29 | 0603 | 3 | 7 | C228062
R22, R26, R30 | 0603 | 3 | 7k | C23101
R3 | 0603 | 1 | 1M | C22935
R4 | 0603 | 1 | 1k | C21190
S4B-PH-K-S_LF__SN_1 | JST_GH_BM04B-GHS-TBT_1x04-1MP_P1.25mm_Vertical | 1 | TELEMETRY | C161692
S4B-PH-K-S_LF__SN_2 | JST_GH_BM04B-GHS-TBT_1x04-1MP_P1.25mm_Vertical | 1 | CAMERA | C161692
SCREWTERMINAL1 | 1725711 | 1 | 1725711 | C5476987
SCREWTERMINAL2 | 1725656 | 1 | BATT | C3029316
SERVO1 | JST_GH_BM03B-GHS-TBT_1x03-1MP_P1.25mm_Vertical | 1 | SERVO1 | C161691
SERVO2 | JST_GH_BM03B-GHS-TBT_1x03-1MP_P1.25mm_Vertical | 1 | SERVO2 | C161691
SERVO3 | JST_GH_BM03B-GHS-TBT_1x03-1MP_P1.25mm_Vertical | 1 | SERVO3 | C161691
SERVO4 | JST_GH_BM03B-GHS-TBT_1x03-1MP_P1.25mm_Vertical | 1 | SERVO4 | C161691
TP1, TP2, TP3 | TestPoint_2Pads_Pitch2.54mm_Drill0.8mm | 3 | TestPoint_2Pole
TPS62111RSAR1 | TPS62111RSAR | 1 | 3.3Vreg | C133558
U-BLOX_ZOE_M8Q-0-1 | UBLOX_ZOE_M8-0-10 | 1 | GPS | C7398634
USB_C_RECEPTACLE_USB2.0_14P1 | USB_C_Receptacle_GCT_USB4110 | 1 | USBc | C5143397
W25Q64JVXGIM_TR1 | SON80P400X400X50-9N | 1 | FLASH | C7398634
Y1 | Crystal_SMD_2012-2Pin_2.0x1.2mm_HandSoldering | 1 | 32.768kHz | C510776
Y3 | Crystal_SMD_2012-2Pin_2.0x1.2mm_HandSoldering | 1 | 32.768kHz | C1985397
Y4 | 830050789 | 1 | 32.768kHz | C7462219
Y5 | XRCGB | 1 | XRCGB24M000F2P29R0 | C7397287

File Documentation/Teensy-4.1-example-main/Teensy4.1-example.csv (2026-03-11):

Source: | /Volumes/Dropbox/Dropbox/Hardware/Teensy4.1-example/Teensy4.1-example.kicad_sch
Date: | 2022 March 08, Tuesday 17:22:59
Tool: | Eeschema (6.0.1-0)
Generator: | /Applications/KiCad/KiCad.app/Contents/SharedSupport/plugins/bom_csv_grouped_by_value.py
Component Count: | 80
Individual Components:
Item | Qty | Reference(s) | Value | LibPart | Footprint | Datasheet | Description | Height | MFGR | MPN | Manufacturer_Name | Manufacturer_Part_Number | Mouser Part Number | Mouser Price/Stock
 |  | C1 | 0.22uf | Device:C | Capacitor_SMD:C_0603_1608Metric | ~ |  |  | Jellybean (X7R or better) | CC0603KRX7R6BB224
 |  | C2 | 0.22uf | Device:C | Capacitor_SMD:C_0603_1608Metric | ~ |  |  | Jellybean (X7R or better) | CC0603KRX7R6BB224
 |  | C3 | 2.2uf | Device:C | Capacitor_SMD:C_0603_1608Metric | ~ |  |  | Jellybean (X7R or better) | CL10B225KP8NNNC
 |  | C4 | 0.22uf | Device:C | Capacitor_SMD:C_0603_1608Metric | ~ |  |  | Jellybean (X7R or better) | CC0603KRX7R6BB224
 |  | C5 | 10000nf | Device:C | Capacitor_SMD:C_0603_1608Metric | ~ |  |  | Jellybean (X7R or better) | 0603B103K160CT
 |  | C6 | 4.7uf | Device:C | Capacitor_SMD:C_0603_1608Metric | ~ |  |  | Jellybean (X7R or better) | CL10B475KQ8NQNC
 |  | C7 | 2.2uf | Device:C | Capacitor_SMD:C_0603_1608Metric | ~ |  |  | Jellybean (X7R or better) | CL10B225KP8NNNC
 |  | C8 | 0.22uf | Device:C | Capacitor_SMD:C_0603_1608Metric | ~ |  |  | Jellybean (X7R or better) | CC0603KRX7R6BB224
 |  | C9 | 10uf | Device:C | Capacitor_SMD:C_0805_2012Metric | ~ |  |  | Jellybean (X7R or better) | GRM21BR71A106KA73K
 |  | C10 | 0.22uf | Device:C | Capacitor_SMD:C_0603_1608Metric | ~ |  |  | Jellybean (X7R or better) | CC0603KRX7R6BB224
 |  | C11 | 10uf | Device:C | Capacitor_SMD:C_0805_2012Metric | ~ |  |  | Jellybean (X7R or better) | GRM21BR71A106KA73K
 |  | C12 | 4.7uf | Device:C | Capacitor_SMD:C_0603_1608Metric | ~ |  |  | Jellybean (X7R or better) | CL10B475KQ8NQNC
 |  | C13 | 0.22uf | Device:C | Capacitor_SMD:C_0603_1608Metric | ~ |  |  | Jellybean (X7R or better) | CC0603KRX7R6BB224
 |  | C14 | 10uf | Device:C | Capacitor_SMD:C_0805_2012Metric | ~ |  |  | Jellybean (X7R or better) | GRM21BR71A106KA73K
 |  | C15 | 4.7uf | Device:C | Capacitor_SMD:C_0603_1608Metric | ~ |  |  | Jellybean (X7R or better) | CL10B475KQ8NQNC
 |  | C16 | 10000nf | Device:C | Capacitor_SMD:C_0603_1608Metric | ~ |  |  | Jellybean (X7R or better) | 0603B103K160CT
 |  | C17 | 0.22uf | Device:C | Capacitor_SMD:C_0603_1608Metric | ~ |  |  | Jellybean (X7R or better) | CC0603KRX7R6BB224
 |  | C18 | 0.22uf | Device:C | Capacitor_SMD:C_0603_1608Metric | ~ |  |  | Jellybean (X7R or better) | CC0603KRX7R6BB224
 |  | C19 | 10pf | Device:C | Capacitor_SMD:C_0603_1608Metric | ~ |  |  | Jellybean (X7R or better) | CC0603KRX7R6BB224
 |  | C20 | 10pf | Device:C | Capacitor_SMD:C_0603_1608Metric | ~ |  |  | Jellybean (X7R or better) | CC0603KRX7R6BB224
 |  | C21 | 9pf | Device:C | Capacitor_SMD:C_0603_1608Metric | ~ |  |  | Jellybean (X7R or better) | GRM1885C1H9R0DA01D
 |  | C22 | 9pf | Device:C | Capacitor_SMD:C_0603_1608Metric | ~ |  |  | Jellybean (X7R or better) | GRM1885C1H9R0DA01D
 |  | C23 | 0.22uf | Device:C | Capacitor_SMD:C_0603_1608Metric | ~ |  |  | Jellybean (X7R or better) | CC0603KRX7R6BB224
 |  | C24 | 4.7uf | Device:C | Capacitor_SMD:C_0603_1608Metric | ~ |  |  | Jellybean (X7R or better) | CL10B475KQ8NQNC
 |  | C25 | 0.22uf | Device:C | Capacitor_SMD:C_0603_1608Metric | ~ |  |  | Jellybean (X7R or better) | CC0603KRX7R6BB224
 |  | C26 | 4.7uf | Device:C | Capacitor_SMD:C_0603_1608Metric | ~ |  |  | Jellybean (X7R or better) | CL10B475KQ8NQNC
 |  | D1 | SP0503BAHT | Power_Protection:SP0503BAHT | Package_TO_SOT_SMD:SOT-143 | http://www.littelfuse.com/~/media/files/littelfuse/technical%20resources/documents/data%20sheets/sp05xxba.pdf
 |  | D2 | LED | Device:LED | LED_SMD:LED_0402_1005Metric | ~
 |  | D3 | LED | Device:LED | LED_SMD:LED_0402_1005Metric | ~
 |  | D4 | LED | Device:LED | LED_SMD:LED_0402_1005Metric | ~
 |  | D5 | BAT54C | Diode:BAT54C | Package_TO_SOT_SMD:SOT-23 | http://www.diodes.com/_files/datasheets/ds11005.pdf
 |  | Di3 | SP0503BAHT | Power_Protection:SP0503BAHT | Package_TO_SOT_SMD:SOT-143 | http://www.littelfuse.com/~/media/files/littelfuse/technical%20resources/documents/data%20sheets/sp05xxba.pdf
 |  | F1 | Fuse | Device:Fuse | Resistor_SMD:R_0805_2012Metric | ~ |  |  | Bel Fuse Inc | 0ZCK0050FF2E
 |  | FB1 | Ferrite_Bead | Device:Ferrite_Bead | Resistor_SMD:R_0805_2012Metric | ~ |  |  | Taiyo Yuden | FBMH2012HM121-T‎
 |  | FB2 | Ferrite_Bead | Device:Ferrite_Bead | Resistor_SMD:R_0805_2012Metric | ~ |  |  | Taiyo Yuden | FBMH2012HM121-T‎
 |  | IC1 | MIMXRT1062DVJ6B | MIMXRT1062DVJ6B:MIMXRT1062DVJ6B | MIMXRT1062DVJ6B:BGA196C80P14X14_1200X1200X152 | https://www.nxp.com/docs/en/nxp/data-sheets/IMXRT1060CEC.pdf | IC MCU 32BIT EXT MEM 196MAPBGA | 1.52 |  |  | NXP | MIMXRT1062DVJ6B | 771-MIMXRT1062DVJ6B | https://www.mouser.co.uk/ProductDetail/NXP-Semiconductors/MIMXRT1062DVJ6B?qs=BJlw7L4Cy7%252B08A9rbTO5WQ%3D%3D
 |  | J1 | Conn_01x11_Male | Connector:Conn_01x11_Male | Connector_PinHeader_2.54mm:PinHeader_1x11_P2.54mm_Vertical | ~
 |  | J2 | Conn_01x11_Male | Connector:Conn_01x11_Male | Connector_PinHeader_2.54mm:PinHeader_1x11_P2.54mm_Vertical | ~
 |  | J3 | Conn_01x12_Male | Connector:Conn_01x12_Male | Connector_PinHeader_2.54mm:PinHeader_1x12_P2.54mm_Vertical | ~
 |  | J4 | Conn_01x11_Male | Connector:Conn_01x11_Male | Connector_PinHeader_2.54mm:PinHeader_1x11_P2.54mm_Vertical | ~
 |  | J5 | Conn_01x11_Male | Connector:Conn_01x11_Male | Connector_PinHeader_2.54mm:PinHeader_1x11_P2.54mm_Vertical | ~
 |  | J6 | Conn_01x03_Male | Connector:Conn_01x03_Male | Connector_PinHeader_2.54mm:PinHeader_1x03_P2.54mm_Vertical | ~
 |  | J7 | Conn_01x03_Male | Connector:Conn_01x03_Male | Connector_PinHeader_2.54mm:PinHeader_1x03_P2.54mm_Vertical | ~
 |  | L1 | 4.7uH | Device:L | Capacitor_SMD:C_0805_2012Metric | ~ |  |  |  | LQM21PN4R7MGRD
 |  | NCP692 | OnSemi NCP692, fixed version | ToyTronics2:OnSemi NCP692, fixed version | Package_DFN_QFN:DFN-6-1EP_3x3mm_P0.95mm_EP1.7x2.6mm | https://www.onsemi.com/pdf/datasheet/ncp690-d.pdf |  |  | Onsemi | NCP692MN33T2G
 |  | P2 | D26 | Connector:TestPoint | Connector_PinHeader_1.00mm:PinHeader_1x01_P1.00mm_Vertical | ~
 |  | PROG1 | SW_Push | Switch:SW_Push | ToyTronics:KMR241GLFS |  |  |  | C&K | KMR241GLFS
 |  | Q1 | Q_PMOS_GDS | Device:Q_PMOS_GDS | Package_TO_SOT_SMD:SOT-23 | ~
 |  | R1 | 5.1k | Device:R | Resistor_SMD:R_0603_1608Metric | ~ |  |  | Jellybean | RC0603FR-075K1L
 |  | R2 | 5.1k | Device:R | Resistor_SMD:R_0603_1608Metric | ~ |  |  | Jellybean | RC0603FR-075K1L
 |  | R3 | 100k | Device:R | Resistor_SMD:R_0603_1608Metric | ~
 |  | R4 | 100k | Device:R | Resistor_SMD:R_0603_1608Metric | ~
 |  | R5 | 1M | Device:R | Resistor_SMD:R_0603_1608Metric | ~
 |  | R6 | 16k | Device:R | Resistor_SMD:R_0603_1608Metric | ~ |  |  | Jellybean
 |  | R7 | 16k | Device:R | Resistor_SMD:R_0603_1608Metric | ~ |  |  | Jellybean
 |  | R8 | 1k | Device:R | Resistor_SMD:R_0402_1005Metric | ~
 |  | R9 | 1M | Device:R | Resistor_SMD:R_0603_1608Metric | ~
 |  | R10 | 1k | Device:R | Resistor_SMD:R_0402_1005Metric | ~
 |  | R11 | 100k | Device:R | Resistor_SMD:R_0603_1608Metric | ~
 |  | R12 | 56k | Device:R | Resistor_SMD:R_0603_1608Metric | ~ |  |  | Jellybean | RMCF0603FT56K0
 |  | R13 | 56k | Device:R | Resistor_SMD:R_0603_1608Metric | ~ |  |  | Jellybean | RMCF0603FT56K0
 |  | R14 | 1k | Device:R | Resistor_SMD:R_0402_1005Metric | ~
 |  | R15 | 2.2M | Device:R | Resistor_SMD:R_0603_1608Metric | ~
 |  | R16 | 100k | Device:R | Resistor_SMD:R_0603_1608Metric | ~
 |  | SWD1 | SWD | Connector:Conn_01x07_Female | Connector_PinHeader_1.27mm:PinHeader_1x07_P1.27mm_Vertical | ~
 |  | TP1 | TestPoint | Connector:TestPoint | TestPoint:TestPoint_Pad_D1.0mm | ~
 |  | TP2 | TestPoint | Connector:TestPoint | TestPoint:TestPoint_Pad_D1.0mm | ~
 |  | TP3 | TestPoint | Connector:TestPoint | TestPoint:TestPoint_Pad_D1.0mm | ~
 |  | TP4 | TestPoint | Connector:TestPoint | TestPoint:TestPoint_Pad_D1.0mm | ~
 |  | TP5 | TestPoint | Connector:TestPoint | TestPoint:TestPoint_Pad_D1.0mm | ~
 |  | TP6 | TestPoint | Connector:TestPoint | TestPoint:TestPoint_Pad_D1.0mm | ~
 |  | TP7 | TestPoint | Connector:TestPoint | TestPoint:TestPoint_Pad_D1.0mm | ~
 |  | U1 | opto_APA102-2020 | APA102:opto_APA102-2020 | USB-C-Power-tester:APA102-2020
 |  | U2 | MAX1562 | MIMXRT1062DVJ6B:MAX1562 | Package_SO:SO-8_5.3x6.2mm_P1.27mm
 |  | U3 | W25Q64JVXGIM | MIMXRT1062DVJ6B:W25Q64VXGIM | MIMXRT1062DVJ6B:XSON8_4x4mm
 |  | U4 | MKL02Z32VFG4 | MCU_NXP_Kinetis:MKL02Z32VFG4 | Package_DFN_QFN:QFN-16-1EP_3x3mm_P0.5mm_EP1.8x1.8mm | http://www.nxp.com/docs/en/data-sheet/KL02P32M48SF0.pdf |  |  | Supplied by Roest Coffee | Custom firmware part
 |  | USB_DFP1 | USB_C_Receptacle_USB2.0 | simonsen:USB_C_Receptacle_USB2.0_NOPOW | USB-C-Power-tester:TYPE-C-31-M-14 | https://www.usb.org/sites/default/files/documents/usb_type-c.zip
 |  | USB_UFP1 | USB_C_Receptacle_USB2.0 | Connector:USB_C_Receptacle_USB2.0 | USB-C-Power-tester:TYPE-C-31-M-14 | https://www.usb.org/sites/default/files/documents/usb_type-c.zip
 |  | Y1 | Crystal_GND23 | Device:Crystal_GND24 | Crystal:Crystal_SMD_Abracon_ABM3B-4Pin_5.0x3.2mm | ~
 |  | Y2 | Crystal | Device:Crystal | Crystal:Crystal_SMD_2012-2Pin_2.0x1.2mm | ~ |  |  | Abracon | ABS06-32.768KHZ-9-1-T
Collated Components:
Item | Qty | Reference(s) | Value | LibPart | Footprint | Datasheet | Description | Height | MFGR | MPN | Manufacturer_Name | Manufacturer_Part_Number | Mouser Part Number | Mouser Price/Stock
1 | 10 | C1, C2, C4, C8, C10, C13, C17, C18, C23, C25 | 0.22uf | Device:C | Capacitor_SMD:C_0603_1608Metric | ~ |  |  | Jellybean (X7R or better) | CC0603KRX7R6BB224
2 | 2 | C3, C7 | 2.2uf | Device:C | Capacitor_SMD:C_0603_1608Metric | ~ |  |  | Jellybean (X7R or better) | CL10B225KP8NNNC
3 | 2 | C5, C16 | 10000nf | Device:C | Capacitor_SMD:C_0603_1608Metric | ~ |  |  | Jellybean (X7R or better) | 0603B103K160CT
4 | 5 | C6, C12, C15, C24, C26 | 4.7uf | Device:C | Capacitor_SMD:C_0603_1608Metric | ~ |  |  | Jellybean (X7R or better) | CL10B475KQ8NQNC
5 | 3 | C9, C11, C14 | 10uf | Device:C | Capacitor_SMD:C_0805_2012Metric | ~ |  |  | Jellybean (X7R or better) | GRM21BR71A106KA73K
6 | 2 | C19, C20 | 10pf | Device:C | Capacitor_SMD:C_0603_1608Metric | ~ |  |  | Jellybean (X7R or better) | CC0603KRX7R6BB224
7 | 2 | C21, C22 | 9pf | Device:C | Capacitor_SMD:C_0603_1608Metric | ~ |  |  | Jellybean (X7R or better) | GRM1885C1H9R0DA01D
8 | 2 | D1, Di3 | SP0503BAHT | Power_Protection:SP0503BAHT | Package_TO_SOT_SMD:SOT-143 | http://www.littelfuse.com/~/media/files/littelfuse/technical%20resources/documents/data%20sheets/sp05xxba.pdf
9 | 3 | D2, D3, D4 | LED | Device:LED | LED_SMD:LED_0402_1005Metric | ~
10 | 1 | D5 | BAT54C | Diode:BAT54C | Package_TO_SOT_SMD:SOT-23 | http://www.diodes.com/_files/datasheets/ds11005.pdf
11 | 1 | F1 | Fuse | Device:Fuse | Resistor_SMD:R_0805_2012Metric | ~ |  |  | Bel Fuse Inc | 0ZCK0050FF2E
12 | 2 | FB1, FB2 | Ferrite_Bead | Device:Ferrite_Bead | Resistor_SMD:R_0805_2012Metric | ~ |  |  | Taiyo Yuden | FBMH2012HM121-T‎
13 | 1 | IC1 | MIMXRT1062DVJ6B | MIMXRT1062DVJ6B:MIMXRT1062DVJ6B | MIMXRT1062DVJ6B:BGA196C80P14X14_1200X1200X152 | https://www.nxp.com/docs/en/nxp/data-sheets/IMXRT1060CEC.pdf | IC MCU 32BIT EXT MEM 196MAPBGA | 1.52 |  |  | NXP | MIMXRT1062DVJ6B | 771-MIMXRT1062DVJ6B | https://www.mouser.co.uk/ProductDetail/NXP-Semiconductors/MIMXRT1062DVJ6B?qs=BJlw7L4Cy7%252B08A9rbTO5WQ%3D%3D
14 | 4 | J1, J2, J4, J5 | Conn_01x11_Male | Connector:Conn_01x11_Male | Connector_PinHeader_2.54mm:PinHeader_1x11_P2.54mm_Vertical | ~
15 | 1 | J3 | Conn_01x12_Male | Connector:Conn_01x12_Male | Connector_PinHeader_2.54mm:PinHeader_1x12_P2.54mm_Vertical | ~
16 | 2 | J6, J7 | Conn_01x03_Male | Connector:Conn_01x03_Male | Connector_PinHeader_2.54mm:PinHeader_1x03_P2.54mm_Vertical | ~
17 | 1 | L1 | 4.7uH | Device:L | Capacitor_SMD:C_0805_2012Metric | ~ |  |  |  | LQM21PN4R7MGRD
18 | 1 | NCP692 | OnSemi NCP692, fixed version | ToyTronics2:OnSemi NCP692, fixed version | Package_DFN_QFN:DFN-6-1EP_3x3mm_P0.95mm_EP1.7x2.6mm | https://www.onsemi.com/pdf/datasheet/ncp690-d.pdf |  |  | Onsemi | NCP692MN33T2G
19 | 1 | P2 | D26 | Connector:TestPoint | Connector_PinHeader_1.00mm:PinHeader_1x01_P1.00mm_Vertical | ~
20 | 1 | PROG1 | SW_Push | Switch:SW_Push | ToyTronics:KMR241GLFS |  |  |  | C&K | KMR241GLFS
21 | 1 | Q1 | Q_PMOS_GDS | Device:Q_PMOS_GDS | Package_TO_SOT_SMD:SOT-23 | ~
22 | 2 | R1, R2 | 5.1k | Device:R | Resistor_SMD:R_0603_1608Metric | ~ |  |  | Jellybean | RC0603FR-075K1L
23 | 4 | R3, R4, R11, R16 | 100k | Device:R | Resistor_SMD:R_0603_1608Metric | ~
24 | 2 | R5, R9 | 1M | Device:R | Resistor_SMD:R_0603_1608Metric | ~
25 | 2 | R6, R7 | 16k | Device:R | Resistor_SMD:R_0603_1608Metric | ~ |  |  | Jellybean
26 | 3 | R8, R10, R14 | 1k | Device:R | Resistor_SMD:R_0402_1005Metric | ~
27 | 2 | R12, R13 | 56k | Device:R | Resistor_SMD:R_0603_1608Metric | ~ |  |  | Jellybean | RMCF0603FT56K0
28 | 1 | R15 | 2.2M | Device:R | Resistor_SMD:R_0603_1608Metric | ~
29 | 1 | SWD1 | SWD | Connector:Conn_01x07_Female | Connector_PinHeader_1.27mm:PinHeader_1x07_P1.27mm_Vertical | ~
30 | 7 | TP1, TP2, TP3, TP4, TP5, TP6, TP7 | TestPoint | Connector:TestPoint | TestPoint:TestPoint_Pad_D1.0mm | ~
31 | 1 | U1 | opto_APA102-2020 | APA102:opto_APA102-2020 | USB-C-Power-tester:APA102-2020
32 | 1 | U2 | MAX1562 | MIMXRT1062DVJ6B:MAX1562 | Package_SO:SO-8_5.3x6.2mm_P1.27mm
33 | 1 | U3 | W25Q64JVXGIM | MIMXRT1062DVJ6B:W25Q64VXGIM | MIMXRT1062DVJ6B:XSON8_4x4mm
34 | 1 | U4 | MKL02Z32VFG4 | MCU_NXP_Kinetis:MKL02Z32VFG4 | Package_DFN_QFN:QFN-16-1EP_3x3mm_P0.5mm_EP1.8x1.8mm | http://www.nxp.com/docs/en/data-sheet/KL02P32M48SF0.pdf |  |  | Supplied by Roest Coffee | Custom firmware part
35 | 1 | USB_DFP1 | USB_C_Receptacle_USB2.0 | simonsen:USB_C_Receptacle_USB2.0_NOPOW | USB-C-Power-tester:TYPE-C-31-M-14 | https://www.usb.org/sites/default/files/documents/usb_type-c.zip
36 | 1 | USB_UFP1 | USB_C_Receptacle_USB2.0 | Connector:USB_C_Receptacle_USB2.0 | USB-C-Power-tester:TYPE-C-31-M-14 | https://www.usb.org/sites/default/files/documents/usb_type-c.zip
37 | 1 | Y1 | Crystal_GND23 | Device:Crystal_GND24 | Crystal:Crystal_SMD_Abracon_ABM3B-4Pin_5.0x3.2mm | ~
38 | 1 | Y2 | Crystal | Device:Crystal | Crystal:Crystal_SMD_2012-2Pin_2.0x1.2mm | ~ |  |  | Abracon | ABS06-32.768KHZ-9-1-T

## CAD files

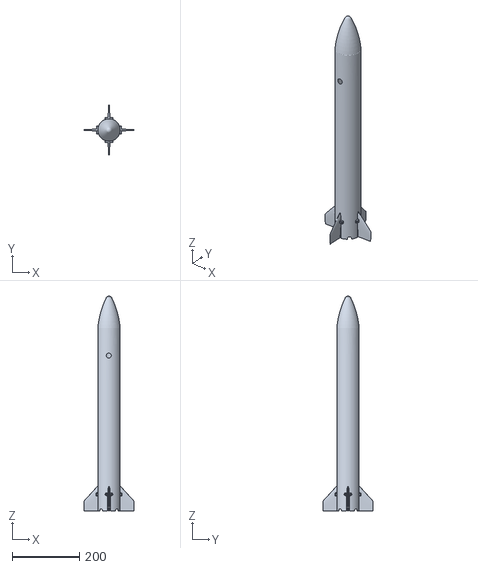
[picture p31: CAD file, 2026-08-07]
GroundStation/assets/rocket.stl
147.7 x 147.7 x 641.1

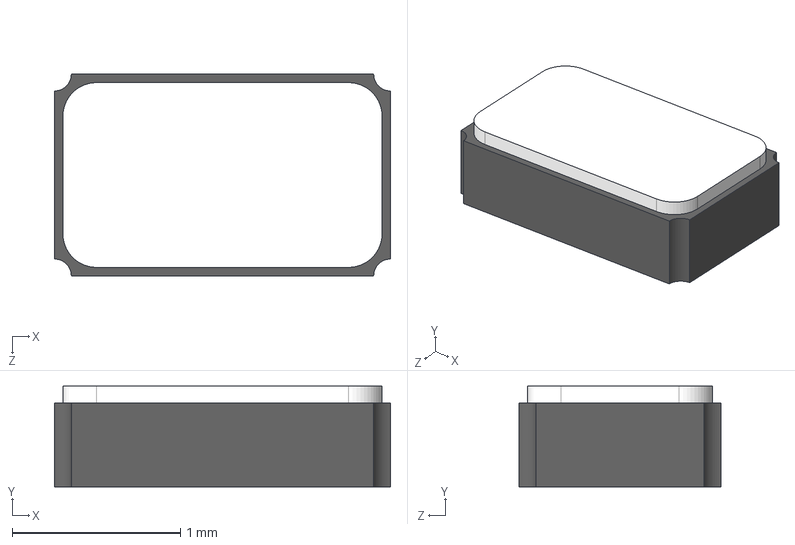
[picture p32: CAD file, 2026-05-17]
PCB/FootsPrints3DModels/ABS06-32.768KHZ-9-1-T.stp
2.00 x 0.6 x 1.20 mm

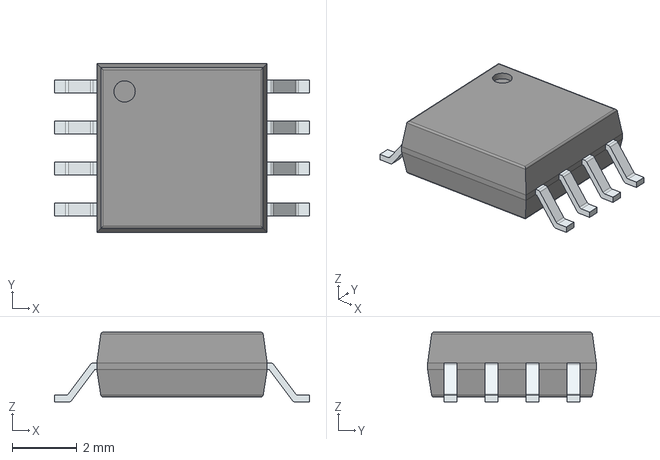
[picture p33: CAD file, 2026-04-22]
PCB/FootsPrints3DModels/GD25Q64ESIG.stp
7.90 x 5.23 x 2.16 mm
PinsArrayLR

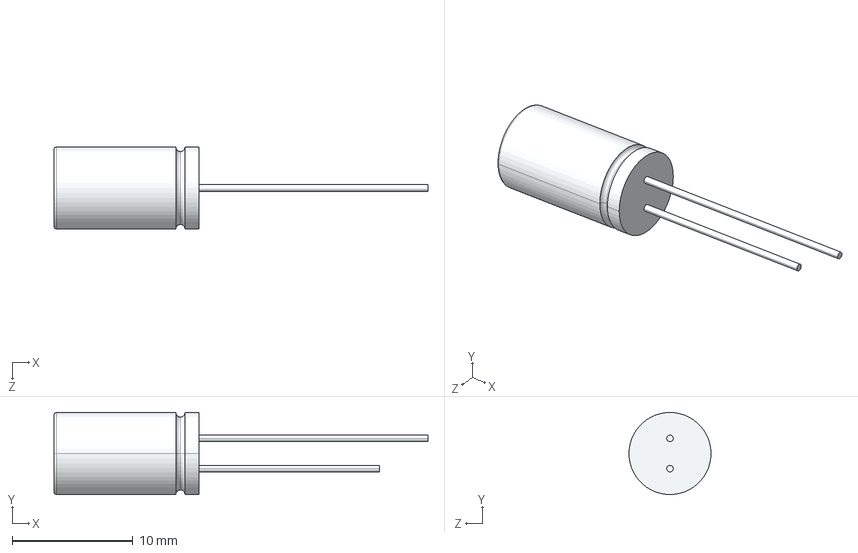
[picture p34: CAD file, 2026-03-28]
PCB/FootsPrints3DModels/A750EQ477M1CAAE015.stp
31.0 x 6.80 x 6.80 mm

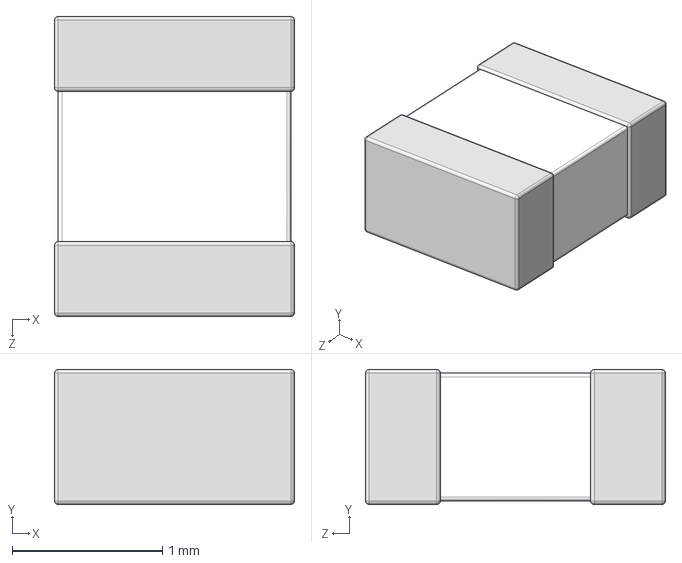
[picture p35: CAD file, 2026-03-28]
PCB/FootsPrints3DModels/LQM2MPN2R2NG0L.stp
1.60 x 0.9 x 2.00 mm

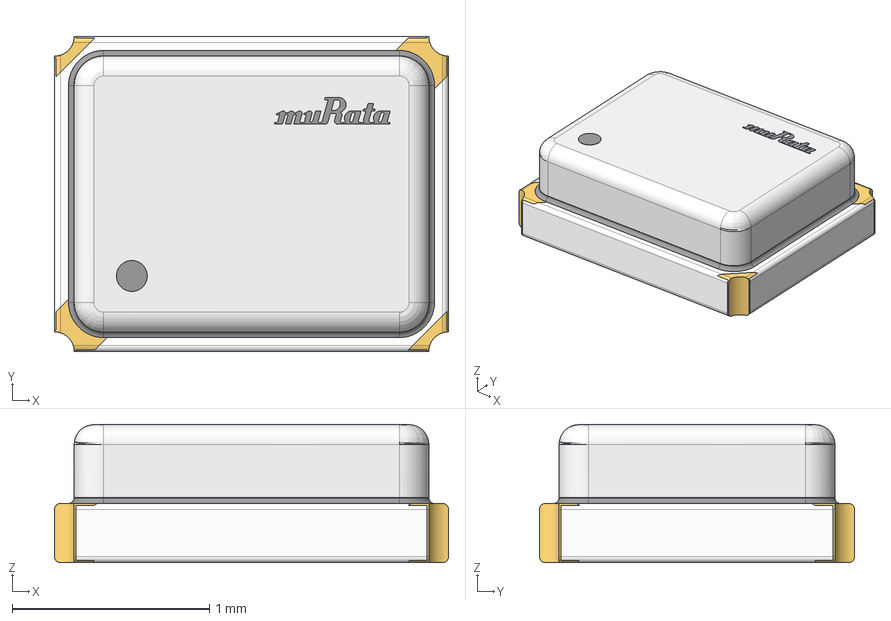
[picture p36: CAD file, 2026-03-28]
PCB/FootsPrints3DModels/XRCGB24M000F2P29R0.stp
2.00 x 1.60 x 0.702 mm

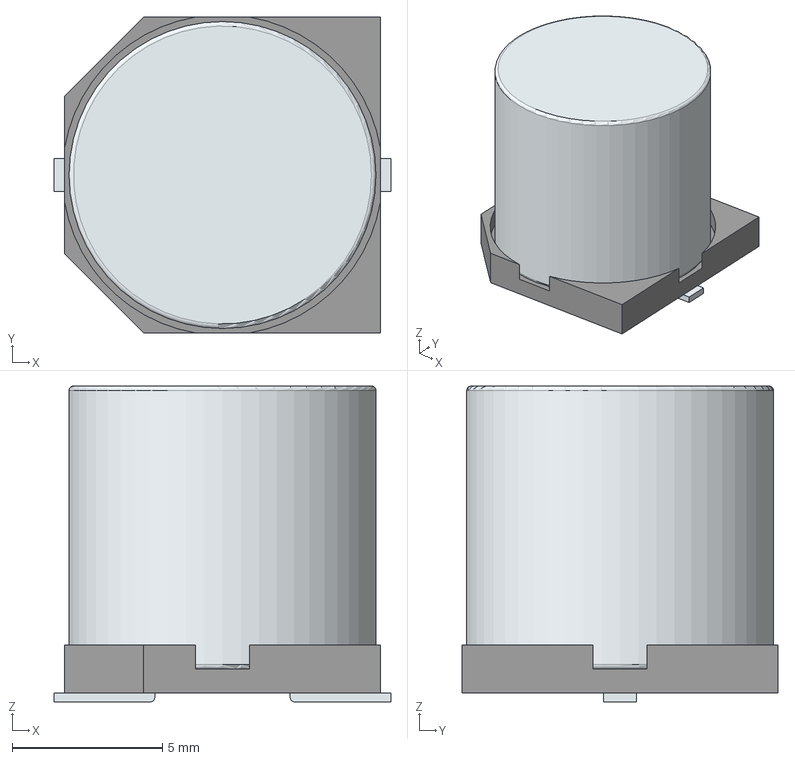
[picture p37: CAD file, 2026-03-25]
PCB/FootsPrints3DModels/EMZR160ARA102MJA0G.stp
11.2 x 10.5 x 10.5 mm
Base
Pin1Fillet
Pin2Fillet

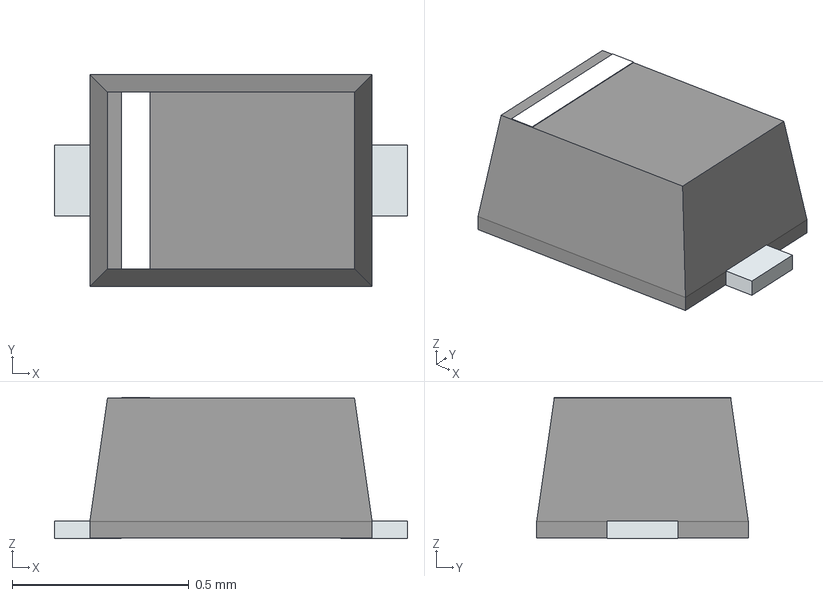
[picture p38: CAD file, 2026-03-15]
PCB/FootsPrints3DModels/ESD9R3.3ST5G.stp
1.00 x 0.6 x 0.4 mm
PinKIdent
PinK
PinA

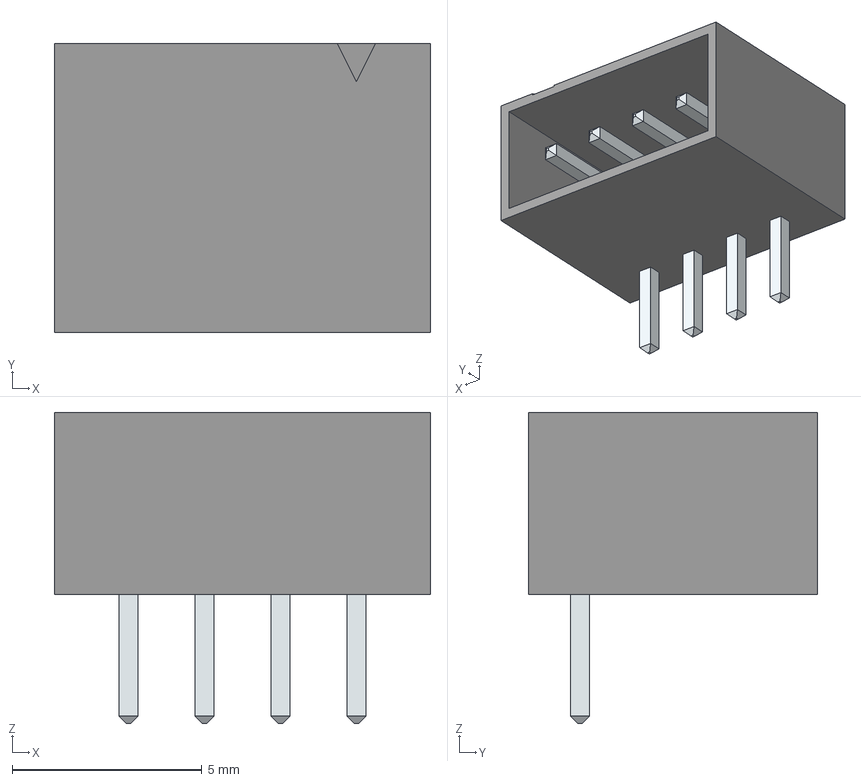
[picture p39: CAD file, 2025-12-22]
PCB/FootsPrints3DModels/S4B-PH-K-S_LF__SN_.stp
9.90 x 7.60 x 8.20 mm
LeadsArray

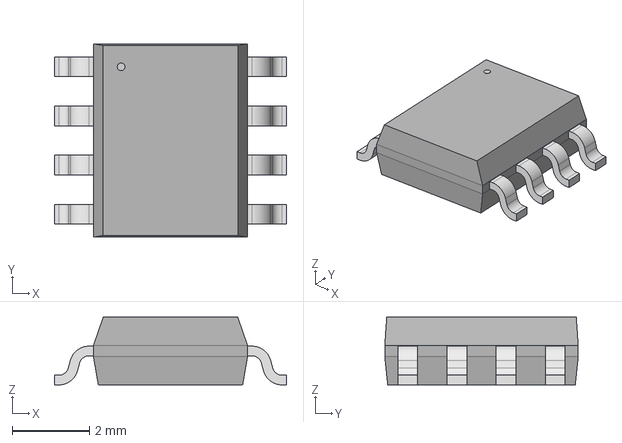
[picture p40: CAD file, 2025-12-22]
PCB/FootsPrints3DModels/APS6404L-3SQR-SN_APY.step
6.00 x 5.00 x 1.75 mm

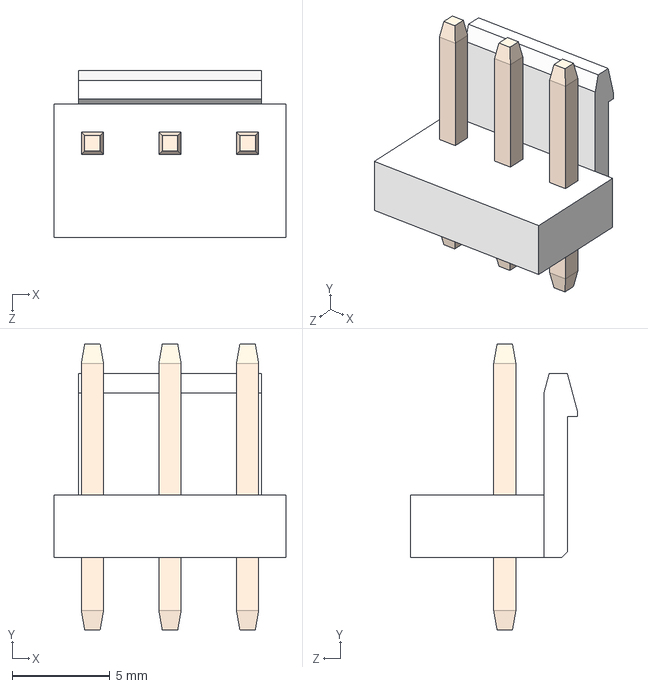
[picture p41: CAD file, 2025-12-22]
PCB/FootsPrints3DModels/B3P-VH_LF__SN_.stp
11.8 x 14.6 x 8.50 mm

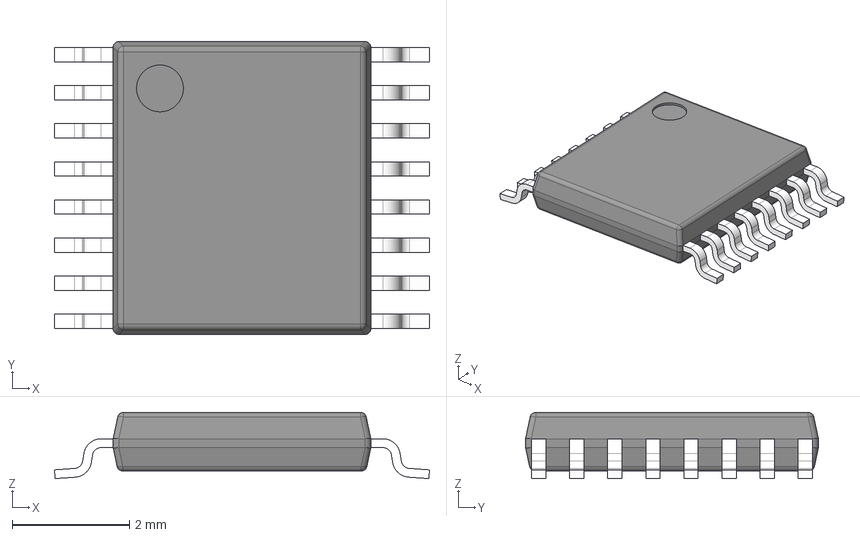
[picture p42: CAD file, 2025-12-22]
PCB/FootsPrints3DModels/INA260AIPWR.stp
6.40 x 5.00 x 1.13 mm
BODY-TSSOP
LEAD-TSSOP x 16
PIN1

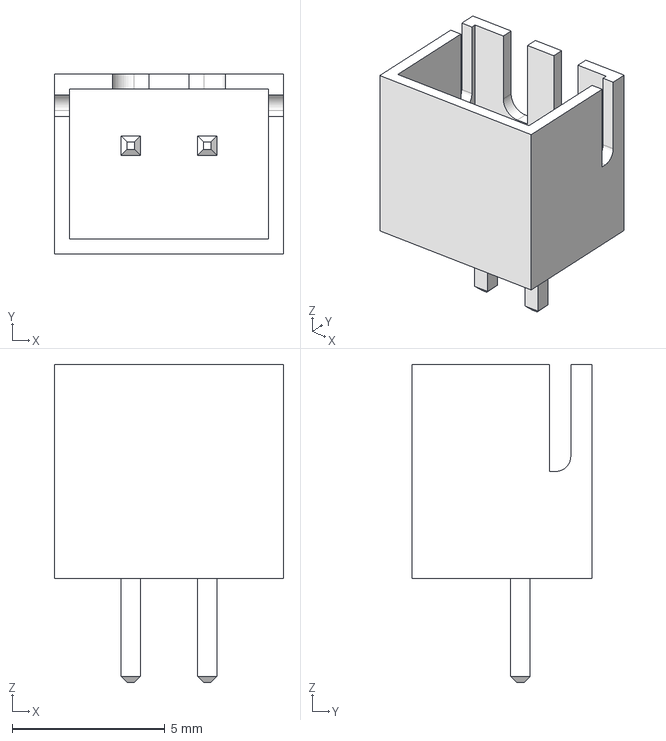
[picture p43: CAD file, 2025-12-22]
PCB/FootsPrints3DModels/JST B2B-XH-A.step
7.50 x 5.90 x 10.4 mm

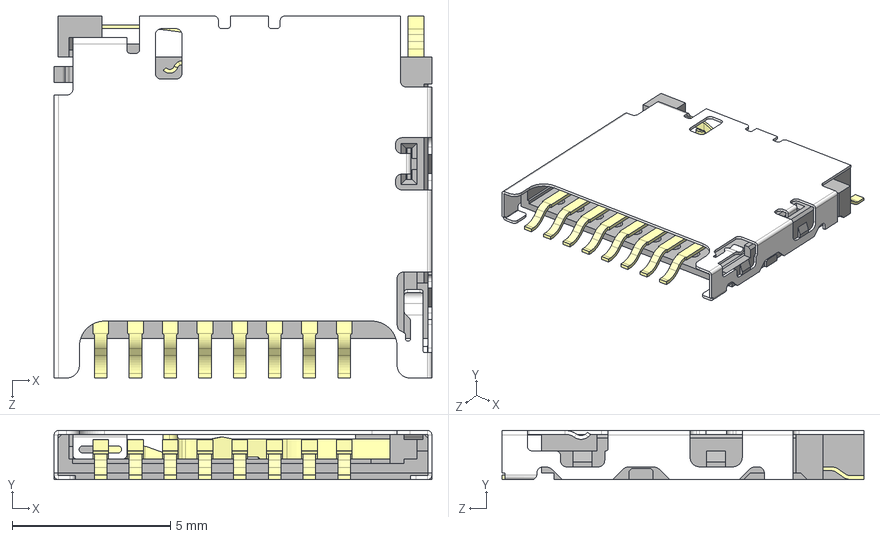
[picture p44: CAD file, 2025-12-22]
PCB/FootsPrints3DModels/DM3D-SF.stp
12.0 x 1.55 x 11.4 mm

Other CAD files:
PCB/FootsPrints3DModels/2.54mm.stp
PCB/FootsPrints3DModels/BNO085.stp
PCB/FootsPrints3DModels/CONN3X1_B3P-VH_JST.step
PCB/FootsPrints3DModels/ADXL375BCCZ.stp
PCB/FootsPrints3DModels/1548130.stp
PCB/FootsPrints3DModels/830050789.stp
PCB/FootsPrints3DModels/BMP390.stp
PCB/FootsPrints3DModels/L102011MS02Q.stp
PCB/FootsPrints3DModels/MIMXRT1062DVL6B.stp
PCB/FootsPrints3DModels/MKL02Z32VFG4.stp
PCB/FootsPrints3DModels/ScrewTerminal_2.54.stp
PCB/FootsPrints3DModels/TPS62111RSAR.stp
PCB/FootsPrints3DModels/TPS62136RGXT.stp
PCB/FootsPrints3DModels/USB4105-GF.STEP
PCB/FootsPrints3DModels/W25Q64JVXGIM_TR.stp
PCB/FootsPrints3DModels/ZOE-M8Q-0.stp

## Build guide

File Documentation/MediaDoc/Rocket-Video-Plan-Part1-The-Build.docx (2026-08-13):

# PART 1: THE BUILD

Video Planning Document — Cinematic Rocket Build Documentary

Working titles (pick one, A/B test the thumbnail):

- "I Spent Years Building a Rocket That Steers Itself — Part 1: The Build"
- "Building a Guided Rocket From Scratch (PCB, Code, Everything)"
- "My Job Made Me an Engineer. This Rocket Proved It."

Theme (the soul of the video, woven into narration, not the title):

Your projects define you, not your work. The rocket waited through graduation, a new career, a new home — and you came back to it. The video is about becoming an engineer twice: once on paper, once at 3am with a knife and a shorted PCB.

Target length: 12–18 minutes

Ending: Assembled rocket + cliffhanger ("Part 2: The Launch")

# The Vibe

Tone: Intimate, cinematic, honest. Not a tutorial. Not a flex. A confession of obsession.

Reference videos to study (watch for pacing, not content):

- BPS.space — how Joe Barnard frames failure as the story
- Stuff Made Here — how he compresses technical work into satisfying montages
- Wintergatan Wednesdays — obsession as narrative fuel
- "I built X" genre openers — the first 15 seconds always show the END result

Visual language:

- Dark, moody workshop shots: desk lamp only, room dark (sells the "3am" feeling)
- Macro shots: solder flowing, knife on trace, servo horns moving, PCB traces
- Screen recordings: KiCad ratsnest untangling, Fusion 360 timelapses, Simulink scopes
- Slow push-ins on the hardware (phone on a slider, or just walk slowly — stabilize in post)
- Natural light for "life" segments vs. artificial light for "obsession" segments — a subtle visual code

Music arc:

- Act 1: curious, light, plucky (discovery)
- Act 2: tense, sparse, low drones (the dead board)
- Act 2 climax: silence → one note → release (the button fix)
- Act 3: building momentum, hopeful (assembly montage)
- Sources: Epidemic Sound, Artlist, or YouTube Audio Library (free)

Narration style: Past tense, first person, conversational. Short sentences during tension. Write the script like you're telling a friend at a bar, then cut 30% of the words.

# Architecture — Three Acts

## Cold Open (0:00–0:45) — Hook before anything else

The single most important 15 seconds of the video.

Shot: The finished rocket, hero shot, slow rotation or slider move. Fins twitch via servo. Cut to the flight computer booting, telemetry appearing on your ground station GUI.

Narration hook (example): "This rocket has a custom flight computer I designed myself, fins that steer it mid-flight, and it almost never existed — because of one button."

Then: Hard cut to black. Title card. Music starts.

Why: Viewers decide in 15 seconds. Show the payoff first, promise the mystery ("one button"), and they'll stay for the story.

## Act 1 — The Dream & The Pause (0:45–4:30)

Emotional job: make the viewer root for you.

### Beat 1 — Day one, the blank page

Story: Opening OpenRocket for the first time. Overwhelmed. Too many disciplines: aerodynamics, electronics, control, mechanics. Using a systems-engineering mindset (your "Lafayette Systems" organization) to break the monster into pieces.

Shots: Screen recording of an empty OpenRocket project → the sim taking shape. Whiteboard or notebook where you sketch the subsystem breakdown (re-create this — film your hand drawing the block diagram). Overhead desk shot.

Narration idea: "I didn't know how to build a rocket. I knew how to build a list."

### Beat 2 — Learning CAD the hard way

Story: No CAD education. What takes others 1 hour takes you 3. Show the ugliness of early attempts.

Shots: Fusion 360 screen recording, timelapse of the body taking shape. If you still have old/bad versions of the model, show them — early clumsy geometry is comedy gold and builds trust.

Narration idea: "Every tutorial made it look easy. It was not easy."

### Beat 3 — Life happens (THE THEME BEAT)

Story: The project stops. Finishing your degree. First engineering job. Moving in with your partner. The rocket waits.

Shots: Change the visual language completely — daylight, real life. Graduation photo, a shot of your work badge or laptop bag, boxes in a new apartment, keys on a counter. The half-finished CAD file sitting closed on the desktop. Dust on a component box (you can stage this).

Narration idea: "I became an engineer at work. But the folder on my desktop kept asking whether I was one at home." (This is where the title's meaning lands. Don't over-explain it. One or two lines, then move on.)

Transition to Act 2: Back to the dark desk. Lamp clicks on. "Then one night, I opened KiCad."

## Act 2 — The Descent & The Knife (4:30–11:00)

Emotional job: tension, despair, catharsis. This is the heart of the video. Spend your best editing here.

### Beat 4 — KiCad, 3am

Story: The hardest part. Learning electronics basics from zero, Teensy 4.1 as the anchor of the design, finishing schematics at 3am with work the next morning.

Shots: Dark room, face lit by monitor. Alarm clock or phone showing 2:47 AM (stage it). KiCad ratsnest → routed board timelapse. Coffee cup. Eyes rubbing. Repeat the "lamp + night" shot 2–3 times across this beat so the audience feels the accumulation of nights.

Narration idea: "I had a degree, a job, and absolutely no idea what a decoupling capacitor was."

### Beat 5 — The $400 bet

Story: Sending the design to PCBWay. Nearly $400. Weeks of doubt while waiting. (Sponsor slot naturally fits here IF you get one — otherwise just tell it straight; the real cost is part of the drama.)

Shots: The order screen with the price (re-record it). Unboxing the PCB — film a real re-unboxing with the actual packaging if you kept it, or shoot tight macro shots of the board coming out of the ESD bag. Your genuine grin — you were happy, let it show.

Narration idea: "Four hundred dollars. For a board designed by a guy who learned electronics on YouTube."

### Beat 6 — It's dead. (THE LOW POINT)

Story: Plug in USB. Nothing. No enumeration. The worst-case theory: bad BGA soldering under the CPU — effectively impossible to fix at home. Discouragement. This is where you almost quit.

Shots: The board connected, PC screen showing no device. Slow zoom on the board. Cut music or drop to a low drone. Sit in this moment — 20–30 seconds of screen time minimum. A shot of you leaning back, hands over face (re-create it; you lived it).

Narration idea: "If the BGA was bad, it was over. You don't reflow a BGA on a kitchen table. Four hundred dollars, months of nights — dead on arrival."

Editing note: Do not rush this beat. The longer the despair, the bigger the payoff.

### Beat 7 — Twelve hours, one button (THE CLIMAX)

Story: 12 hours of debugging. Then the idea: check the program button. It's shorted. One cut with a knife across the trace. It enumerates. IT WORKS.

Shots: Multimeter probing (macro). The schematic on screen, zooming to the button. THE HERO SHOT: macro of the knife cutting the trace — re-create this on camera, slow, deliberate. Then: USB plug in → the connect sound / device appearing on screen → your reaction. And the trump card: show the actual scar on the actual board today. Point at it. "This cut is still there."

Narration idea: "Twelve hours of debugging. And the answer was a button. One shorted button, one knife, one cut." (Pause. Let the connect chime play in silence.) "It worked."

Editing note: Silence right before the fix. Music explodes (or comes back warm) right after. This contrast IS the emotional payoff of the entire video.

## Act 3 — Momentum (11:00–15:30)

Emotional job: reward the viewer. Fast, satisfying, fun.

### Beat 8 — The proof-of-life montage

Story: Sensors come alive one by one — barometer, accelerometer, IMU. Compress the sensor tests, telemetry, the ground station GUI, and the C++ flight code into this montage.

Shots: Rapid cuts: serial monitor scrolling data, plots reacting when you lift/shake the board, the GUI receiving telemetry across the room, code editor with your actual flight code, Simulink control-loop scopes responding.

Montage rule: Each clip 1–3 seconds, cut on the beat of the music, minimal narration. One line each max: "Barometer. Alive. Accelerometer. Alive."

### Beat 9 — Small defeats, kept in

Story: The 6-hour print that failed. Components trickling in, wallet bleeding. These keep Act 3 human so it's not just a victory lap.

Shots: The failed print (if you kept the spaghetti — if not, a short reprint failure or just the pile of supports works), timelapse of the successful avionics bay print, a growing pile of delivery packages (stage a "package pile" shot), parachute unfolding.

Narration idea: "Six hours of printing. Fell apart at hour six. That's fine. Everything in this project failed once before it worked."

### Beat 10 — Assembly + Cliffhanger ending

Story: Where you are now: assembling the electronics into the airframe, finishing the flight code.

Shots: The most cinematic sequence of the video — the avionics bay sliding into the body, fins attached, servos twitching in a fin-control test, the full rocket standing. End on the same hero shot as the cold open — but now the viewer knows what it cost.

Closing narration idea: "Two years ago this was a sketch and a guy who didn't know what a decoupling capacitor was. It's real now. Next question: will it fly?" (Beat.) "Part 2: the launch."

End card: Subscribe prompt framed as "come see it fly."

# Master Shot List (film these — check them off)

### Hero / beauty shots

- Finished rocket, slow rotation or slider, dark background, single light
- Fin servo actuation close-up (fins twitching)
- Flight computer macro: traces, CPU, connectors
- THE KNIFE SCAR on the PCB (today, real) — your most valuable shot
- Ground station GUI receiving live telemetry

### Re-creation shots (true events, re-shot)

- Hand sketching subsystem block diagram in notebook
- Dark room, monitor-lit face, clock at ~3am
- Multimeter probing the board
- Knife cutting a trace (macro, slow) — use a scrap PCB if you don't want to touch the real one again
- USB plug-in → device connect sound/screen
- Leaning back, hands on face (the despair shot)
- Unboxing / ESD bag reveal of the PCB
- Dust-on-box "the project waited" shot

### Screen recordings

- OpenRocket: blank project → full sim
- Fusion 360 modeling timelapse (Fusion has a built-in design timeline replay — use it)
- KiCad: schematic + ratsnest → routed board
- Simulink control loop + scopes
- C++ flight code scrolling / being written
- Serial monitor sensor data reacting to movement
- PCBWay order page with the ~$400 total

### Process / B-roll

- 3D print timelapse (avionics bay) + failed print evidence
- Soldering macro (solder flowing on a pad)
- Package pile / components arriving
- Parachute unfold
- Assembly sequence: bay sliding into airframe, fins on

### Life segments (daylight)

- Graduation photo / work badge / laptop bag
- New home: keys, boxes (even symbolic re-creations)

# Practical Notes for a First-Time Filmmaker

### Gear — you need less than you think

- A phone with 4K is enough. Lock exposure and focus before every shot.
- One cheap desk lamp + dark room = the entire Act 2 look.
- A $20 phone tripod, and a macro clip-on lens (~$15) for solder/trace shots.
- Record narration separately, in a closet or under a duvet (kills echo), phone 15 cm from your mouth. Audio quality matters more than video quality.

### Workflow that actually works

1. Write the narration script FIRST (aim ~1,800–2,200 words for 15 min).
2. Record the narration.
3. Edit the narration audio into a timeline — this is your skeleton.
4. Film/collect shots to cover every sentence. If a sentence has no shot, film one or cut the sentence.
5. Music last, mixed low under narration (-15 to -20 dB relative).

Editing software: DaVinci Resolve (free version is fully sufficient).

### Rules to protect the vibe

- Never explain a technical thing for more than 20 seconds unless it serves the story. Curious viewers get Part 2 / a technical follow-up video.
- Every beat must answer: "what did this cost me, or what did it teach me?" If neither — montage or cut.
- Show your face at least a few times. Faceless engineering videos underperform; people subscribe to people.
- Keep one honest imperfect moment per act. Polish everywhere kills trust.

Thumbnail direction: You holding the rocket or the bare flight computer, dark background, one strong light, genuine expression (not the fake shocked face). Optional text: "From scratch." Max 3 words on a thumbnail.

# What NOT To Do

- Don't invent struggles that didn't happen — you have enough real ones. Re-creating real events: yes. Fabricating fake ones: no. Viewers smell it.
- Don't title it with the philosophy. The theme lives in the narration.
- Don't walk through the build chronologically step-by-step. Structure by emotion, compress by montage.
- Don't end without a clear promise of Part 2. The cliffhanger is your subscriber engine.

# Next Steps Checklist

- Write the narration script (use the beat structure above, one paragraph per beat)
- Record scratch narration on your phone, listen back, cut 30%
- Film the re-creation shots (one weekend: a "dark desk" day + a "macro/hardware" day)
- Capture all screen recordings
- From now on: film EVERYTHING you do on the rocket — Part 2 will be 100% real footage
- Rough cut → show it to your partner → fix what confuses them
- Music, color, thumbnail, publish

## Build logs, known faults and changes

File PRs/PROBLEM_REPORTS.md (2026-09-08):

# RocketPower — Problem Reports Log

Tracks known, unresolved hardware/firmware problems so investigation already
done isn't repeated or lost before the V&V campaign. Each entry: symptom,
what's been ruled out, current root-cause conclusion (if any), current
mitigation (if any), and what's left to actually close it.

When a PR is fixed: move its entry to the **Resolved** section at the bottom
with the resolution, don't delete it — the ruled-out list is often the most
valuable part for the next person (or future you) hitting something similar.

Last updated: 2026-09-08

---

## OPEN

### PR-001 — ADXL375 (200g accelerometer) reads non-physical noise at rest
**Status:** OPEN — root cause narrowed to hardware, not yet fixed
**Severity:** High (currently worked around; see mitigation)

**Symptom:** Magnitude swings between ~0.3g and 8g+ while the board sits
stationary on the bench. Should read a steady ~1.0g.

**Ruled out (each via a real bench test, not assumption):**
- LoRa/RF coupling — telemetry radio physically disconnected, noise unchanged
- I2C bus clock speed — reverted Wire2 400kHz → 100kHz, no change
- Torn multi-register reads — real bug found (`getEvent()`'s 3 separate I2C
  reads vs `getXYZ()`'s atomic burst read), fixed, did **not** resolve the
  noise (a real bug, just not the cause of this symptom)
- CS pin floating — user confirmed tied HIGH via 10kΩ to 3.3V on the schematic
- Table/mechanical vibration — user confirmed table motionless, PCB-mounted
- SELF_TEST register stuck set — read back directly: `DATA_FORMAT=0b00001011`,
  bit 7 clear
- SD card electrical proximity — card physically removed, no change
- ODR/bandwidth — swept the full range (1.56Hz, 100Hz, 3200Hz). Noise scaled
  in the expected direction (worse at 3200Hz, ~8g swings) but **did not
  disappear at 1.56Hz**, where datasheet-predicted noise is <6mg (should have
  been silent if this were ordinary sensor noise) — this is the test that
  conclusively rules out "just noise," at any bandwidth

**Conclusion:** hardware-layer fault specific to this unit/board — most
likely a marginal solder joint (intermittent contact reads exactly like this)
or a genuinely defective chip. Not fixable in software.

**Current mitigation (temporary, see `config.h`'s `TEMPORARY` comments for
exact revert instructions):**
- `StateMachine.cpp`/`BackupDeploy.cpp`'s liftoff/burnout gating switched
  from `highg_mag_g` (ADXL375) to `accel_mag_ms2` (BNO085
  `SH2_LINEAR_ACCELERATION`, gravity-removed) — safe because both thresholds
  (`IMU_LIFTOFF_ACCEL_THRESHOLD_MS2`=15.0, `IMU_BURNOUT_ACCEL_THRESHOLD_MS2`=2.0)
  sit far below the BNO085's clip ceiling
- Telemetry `accel_x/y/z_cg` also switched to the same BNO085 source
- ADXL375 is still read/logged/telemetried every loop (`highg_x/y/z_g`,
  `highg_mag_g`) for continued visibility, just no longer trusted for flight
  logic

**Known limitation of the mitigation:** the BNO085's onboard accelerometer is
a **fixed ±8g range** (confirmed in the CEVA/Bosch BNO08X datasheet, not
configurable). The current up-to-date OpenRocket simulation (Simulation 1/3
in `RocketPower_V1.ork`) predicts a peak boost acceleration of ~11.7g — above
that ceiling. This does **not** affect liftoff/burnout gating (thresholds are
far below 8g either way), but it means telemetry accel values and the
velocity-fusion IMU-integration step will clip/saturate near 8g during the
~1-2s of peak thrust until the ADXL375 is fixed. Data-quality gap only, not a
safety gap.

**Remaining actions:**
- [ ] Physically inspect/reflow the ADXL375's solder joints
- [ ] Swap-test with a spare ADXL375 unit if one becomes available
- [ ] Once fixed: revert `StateMachine.cpp`, `BackupDeploy.cpp`,
      `TelemetryManager.cpp` back to the ADXL375 source (search `TEMPORARY`
      in those files + `config.h`)

---

### PR-002 — Barometer readings corrupted by RF coupling during LoRa TX
**Status:** OPEN — root cause confirmed, only software-mitigated (not fixed
at the hardware level)
**Severity:** Medium (mitigated for flight-critical use, raw data still bad)

**Symptom:** Barometer-derived vertical velocity showed multi-m/s noise
spikes at rest, correlated with LoRa transmit activity ("super reactive to
the barometer").

**Investigation:**
- Bench capacitor swaps (100µF, 220µF+100µF parallel, 220µF alone, 470µF)
  tried on the barometer's supply rail — inconclusive/didn't fix it
- Disabling LoRa telemetry entirely (software) made the noise disappear —
  confirmed
- Physically disconnecting the telemetry radio also cleared it — confirmed
- **Root cause: RF/antenna-proximity coupling into the barometer**, not a
  power-rail issue as originally suspected (the capacitor changes were never
  the actual fix)

**Current mitigation (software only, protects the *fused* velocity, not the
raw sensor):**
- Complementary filter retuned (`VERT_VEL_ALPHA` 0.98 → 0.999) — math-derived
  in `config.h`'s comment (steady-state noise ≈ `sqrt(β/2)×σ` for a filter
  fed fresh noisy corrections every cycle)
- `MAX_PLAUSIBLE_VERT_SPEED_MS` (350 m/s) sanity gate added — rejects a
  single extreme RF-glitch baro sample outright rather than blending it in

**Remaining/open concern:** raw `baro_alt_m`/`pressure_hpa` are **not**
protected by the above — they're still noisy at the source whenever LoRa is
transmitting. `StateMachine::DESCENT`'s landed-detection reads raw
`baro_alt_m` directly (`fabsf(d.baro_alt_m - _landedRefAlt) <
LANDED_ALT_TOLERANCE_M`), not the fused/filtered value. **Needs explicit V&V
testing:** confirm LANDED detection isn't falsely delayed or re-triggered by
RF noise while telemetry is actively transmitting during descent.

**Remaining actions:**
- [ ] V&V test: verify DESCENT/LANDED behavior with telemetry actively
      transmitting, not just on the bench with it disabled
- [ ] Consider a hardware fix (ferrite bead / series resistor on the
      barometer's supply or signal lines, or antenna relocation/shielding) —
      discussed, never implemented
- [ ] If hardware fix lands, confirm whether `VERT_VEL_ALPHA`/
      `MAX_PLAUSIBLE_VERT_SPEED_MS` can be tightened back up

---

### PR-003 — SERVO_PREFLIGHT / SERVO_TEST commands lack flight-state gating
**Status:** OPEN — identified in full-project audit, not yet fixed
**Severity:** High (could freeze the flight loop mid-flight)

**Symptom (risk, not yet observed in the field):** `SERVO_PREFLIGHT` is a
blocking ~6s all-4-channel choreography; `SERVO_TEST` is a blocking sweep.
Neither checks the current `FlightState` before running. If either command
reaches the flight computer while armed or mid-flight (accidental ground
send, a duplicated/misrouted command), the main loop freezes for the
duration — no sensor reads, no telemetry, no state-machine updates — during
active flight.

**Remaining actions:**
- [ ] Add a flight-state guard in `TelemetryManager::_handleCommand()` (e.g.
      only allow `SERVO_PREFLIGHT`/`SERVO_TEST` when `state == IDLE` or
      `ARMED`-but-not-yet-launched; reject and log otherwise)
- [ ] Decide whether `SERVO_CENTER_ALL`/nudge commands need the same
      treatment (lower risk — non-blocking — but worth a deliberate decision,
      not an oversight)

---

### PR-004 — E22-900T22D can't be reconfigured in-circuit (M0/M1 hardwired to GND)
**Status:** OPEN — requires a PCB revision, not a firmware-only fix
**Severity:** Medium (telemetry works fine as-is; this blocks improving it)

**Symptom:** Air data rate is stuck at the factory default 2.4kbps, capping
reliable telemetry at ~1Hz (see `TELEMETRY_INTERVAL_MS`'s comment in
`config.h`). Investigated raising it (module supports up to 62.5kbps, see
the official E22-900T22D user manual) — the rate/UART-baud/parity live in
one register (REG0, address 0x03), changeable with a single `C0 03 01 <val>`
write command. But reaching **Configuration Mode** (Mode 2: M1=1, M0=0) to
send that command requires driving the module's M0 and M1 pins, and **this
board hardwires both directly to GND in copper** (`LORA_M0_PIN`/`M1_PIN` =
-1 in `config.h` — not just unrouted to the MCU, permanently tied on the
PCB itself), locking it in Mode 0 (Normal) forever.

**What's confirmed NOT needed:** the existing 4-pin JST-GH connection
(TXD/RXD/GND/VCC) is already everything required for the data link itself
at any air rate/baud — that doesn't change. Only two new control signals
(M0, M1) are needed to unlock in-circuit reconfiguration. AUX (busy/ready
handshake) is optional — a fixed settle-time delay can substitute for it if
pin budget is tight, so the real minimum is 2 pins, not 3.

**Blocker:** no spare/free GPIO currently available on this board's
existing routing to wire M0/M1 to. Needs checking against the actual
schematic for a genuinely unused MIMXRT1062 pad (the chip has far more
GPIOs than this board's headers/silkscreen currently expose) rather than
assuming none exist — or freeing up two pins by reassigning a
lower-priority function.

**Current workaround (works, but is a bench-only, every-time-you-want-to-
change-it procedure):** unplug the module's JST-GH cable, wire it to an
external 3.3V-logic USB-TTL adapter with jumpers forcing M1=3.3V/M0=GND,
send the config command at 9600 8N1 (fixed rate the module always uses in
Configuration Mode regardless of its stored operating baud), then restore
M0/M1 to GND and reconnect. No in-field or in-software reconfigurability
with this workaround — every future rate change means physically pulling
the module again.

**Remaining actions:**
- [ ] Audit the schematic for a genuinely free MIMXRT1062 GPIO pad (not
      just "no free header pin") — check `main.kicad_sch` and
      `HighCurrentComponents.kicad_sch` for what's actually unused
- [ ] If none exist, decide what lower-priority function to give up (or
      multiplex) to free 2 pins
- [ ] Next PCB rev: route M0/M1 from the E22 module's pads to those 2 GPIOs
      instead of tying them to GND; add pull-downs so the module still
      defaults to Mode 0 (Normal) if those pins are ever left floating
      (e.g. before the MCU's GPIOs are initialized at boot)
- [ ] Firmware: add `LORA_M0_PIN`/`LORA_M1_PIN` real pin numbers to
      `config.h`, add a one-time (or ground-commanded) config-mode routine
      to `LoRaRadio` that drives Mode 2, sends the REG0 write, confirms via
      read-back, then returns to Mode 0
- [ ] Once wired: revisit the air-rate/interval choice (9.6kbps / REG0=0xE4
      was the conservative first pick given a ~1km max range requirement,
      see chat history — field-test range before committing further)

---

## Resolved this session (reference — not exhaustive project history)

Kept short and only for items that came up as candidate PRs during this same
investigation pass, so they aren't second-guessed or re-investigated later.

- **Serial vs DEBUG_SERIAL bug** — was present in `LoRa.cpp`,
  `TelemetryManager.cpp`, `StateMachine.cpp`, `PyroController.cpp`,
  `FinController.cpp`, `CameraController.cpp`, `BackupDeploy.cpp`. All fixed;
  every plain debug print now goes to `DEBUG_SERIAL`.
- **BackupDeploy's `WAITING_FOR_ALTITUDE` had no timeout** — could get
  permanently stuck on one bad baro sample, silently disabling the entire
  backup-deploy safety net for the rest of the flight. Fixed with
  `BACKUP_ALTITUDE_TIMEOUT_MS` (45s) — re-arms `WAITING_FOR_BOOST` on
  timeout instead of forcing the apogee watch open.
- **README's Flight Procedure link broken** — both `README.md` files
  deleted outright (proper ones to be written at the end of the V&V
  campaign, per the user's call).
- **Unused config.h defines** — `GPS_DEBUG_RAW_NMEA` was dead (never wired
  up); now actually echoes raw NMEA to `DEBUG_SERIAL` when enabled.
  `SERVO_NUM_CHANNELS` was defined but ignored (`FinController` hardcoded
  `4` everywhere); now used consistently. `LORA_M0/M1/AUX_PIN`,
  `LORA_CHANNEL` left as-is — legitimate hardware documentation, not bugs.
  `PYRO_IGNITION` was already gone from the earlier pyro-channel remap.
- **Accelerometer.cpp hardcoded `Wire2`** instead of `ADXL375_I2C_BUS` —
  fixed; changing that macro now actually takes effect.
- **config.h's I2C Bus Assignments section was split in two** by later
  insertions — reordered back to contiguous.
- **FlightStates.h called the apogee event "drogue"** while the only
  channel is `PYRO_PARACHUTE` — this is a single-deploy design, "drogue"
  incorrectly implied an unbuilt dual-deploy stage. Renamed to "parachute".
- **FinController.h's file comment** was old investigation-journal style —
  condensed to current terse convention.

---

## Deferred / proposed (not problems — don't confuse with the PR list above)

- **Barometer/IMU-based liftoff cross-check**: offered twice during the
  ADXL375 investigation as a second independent liftoff signal. User hasn't
  said yes/no yet — not started.

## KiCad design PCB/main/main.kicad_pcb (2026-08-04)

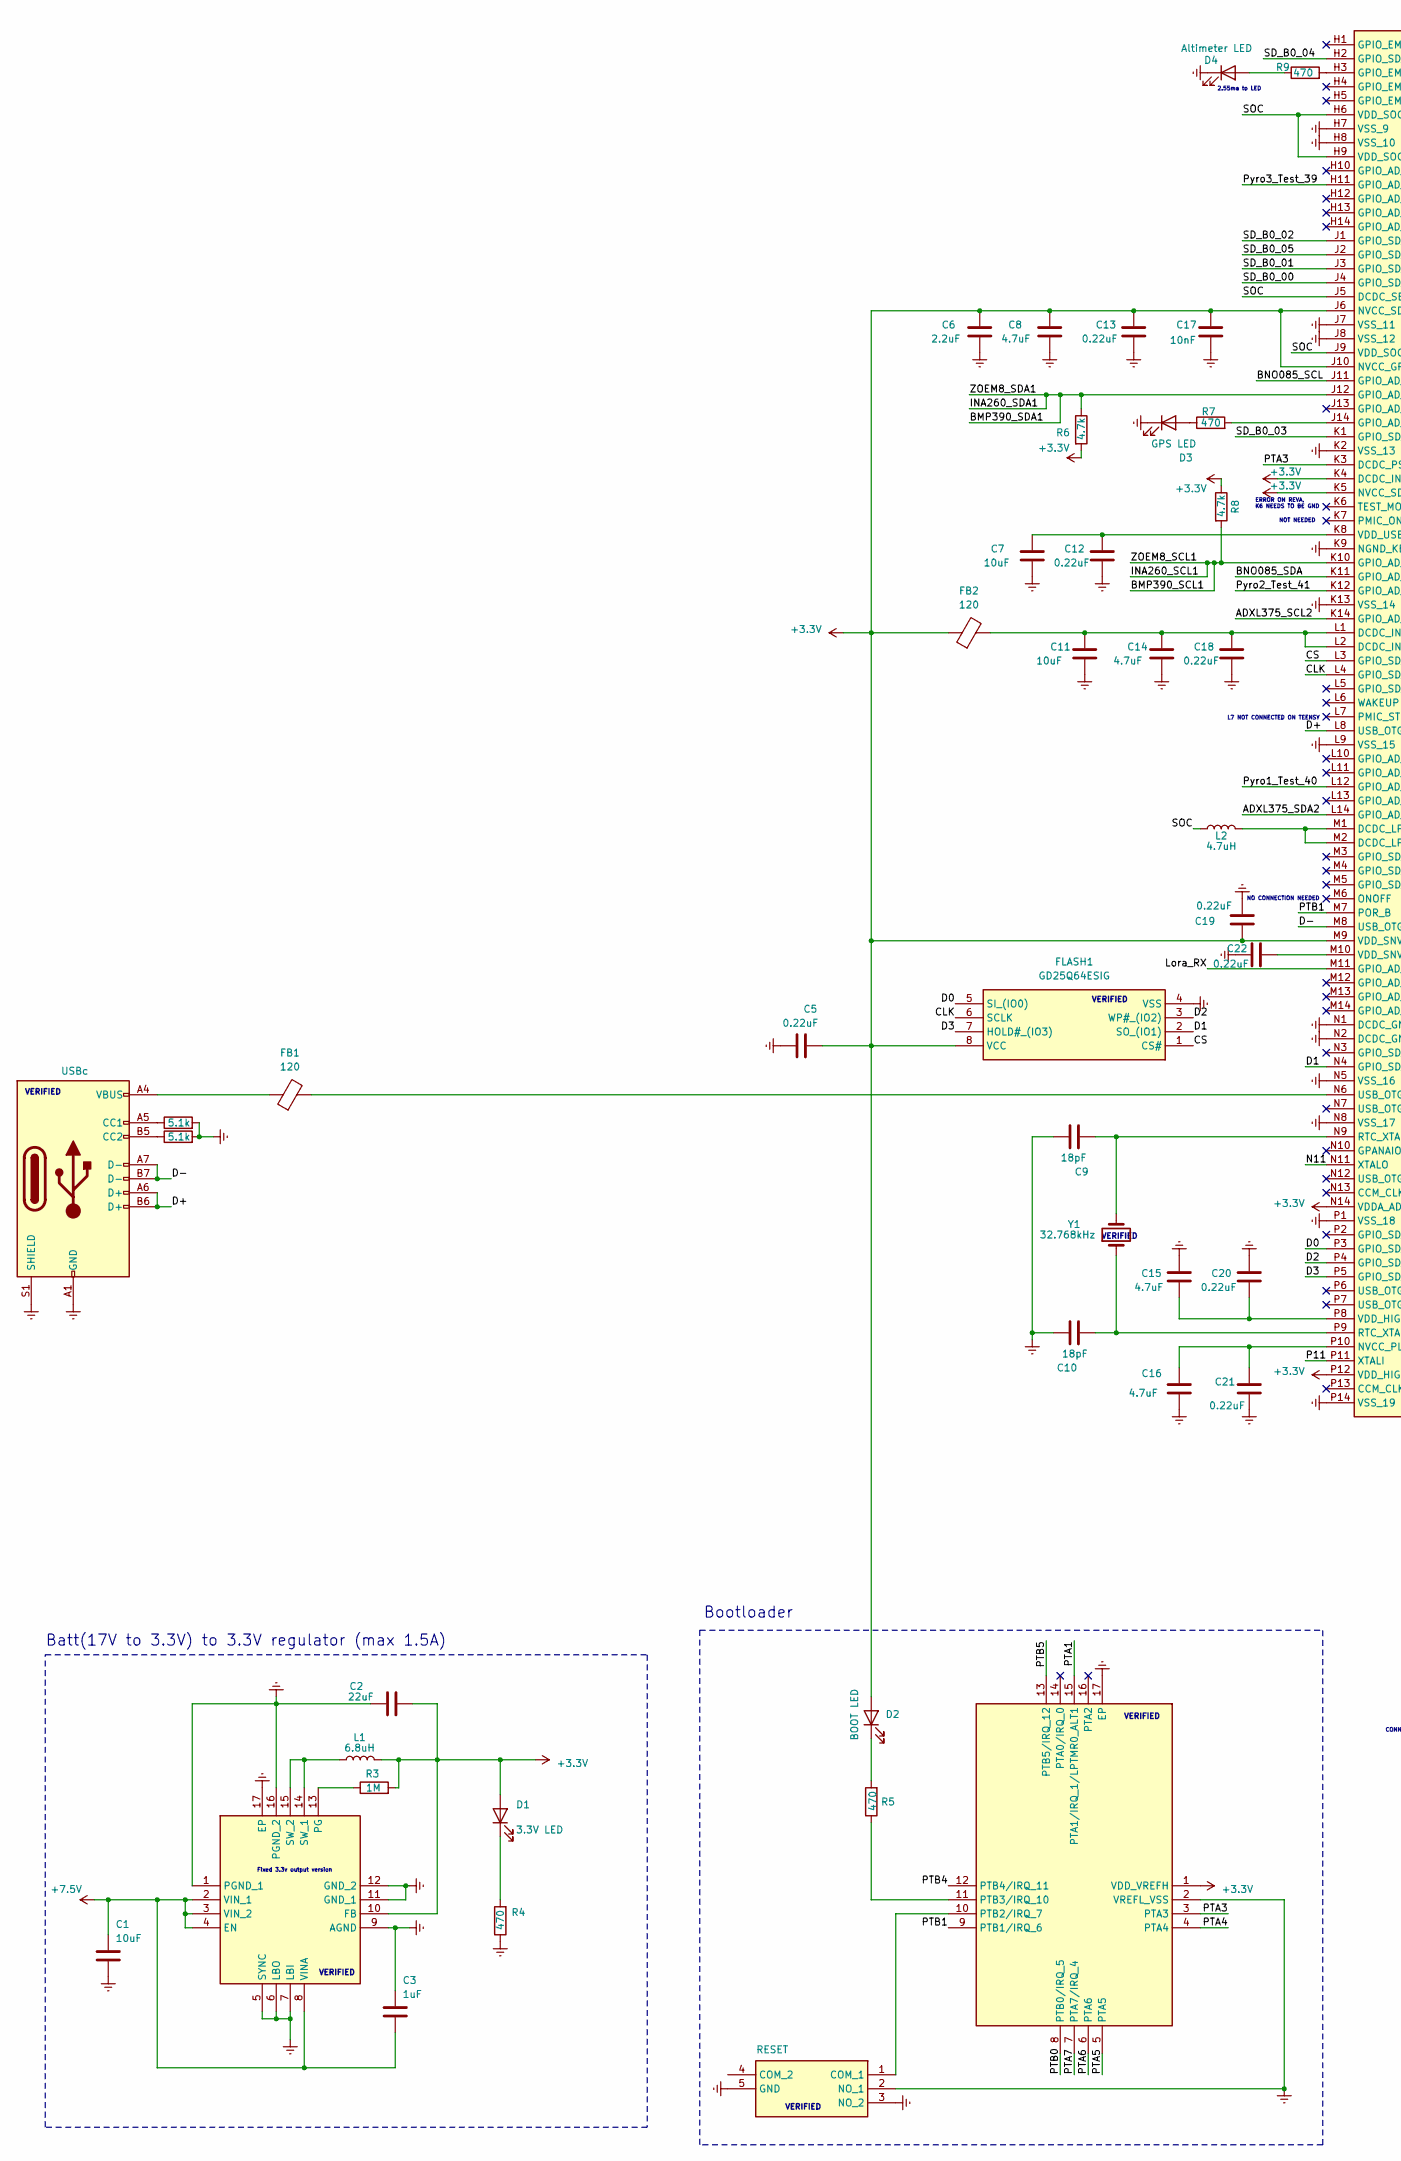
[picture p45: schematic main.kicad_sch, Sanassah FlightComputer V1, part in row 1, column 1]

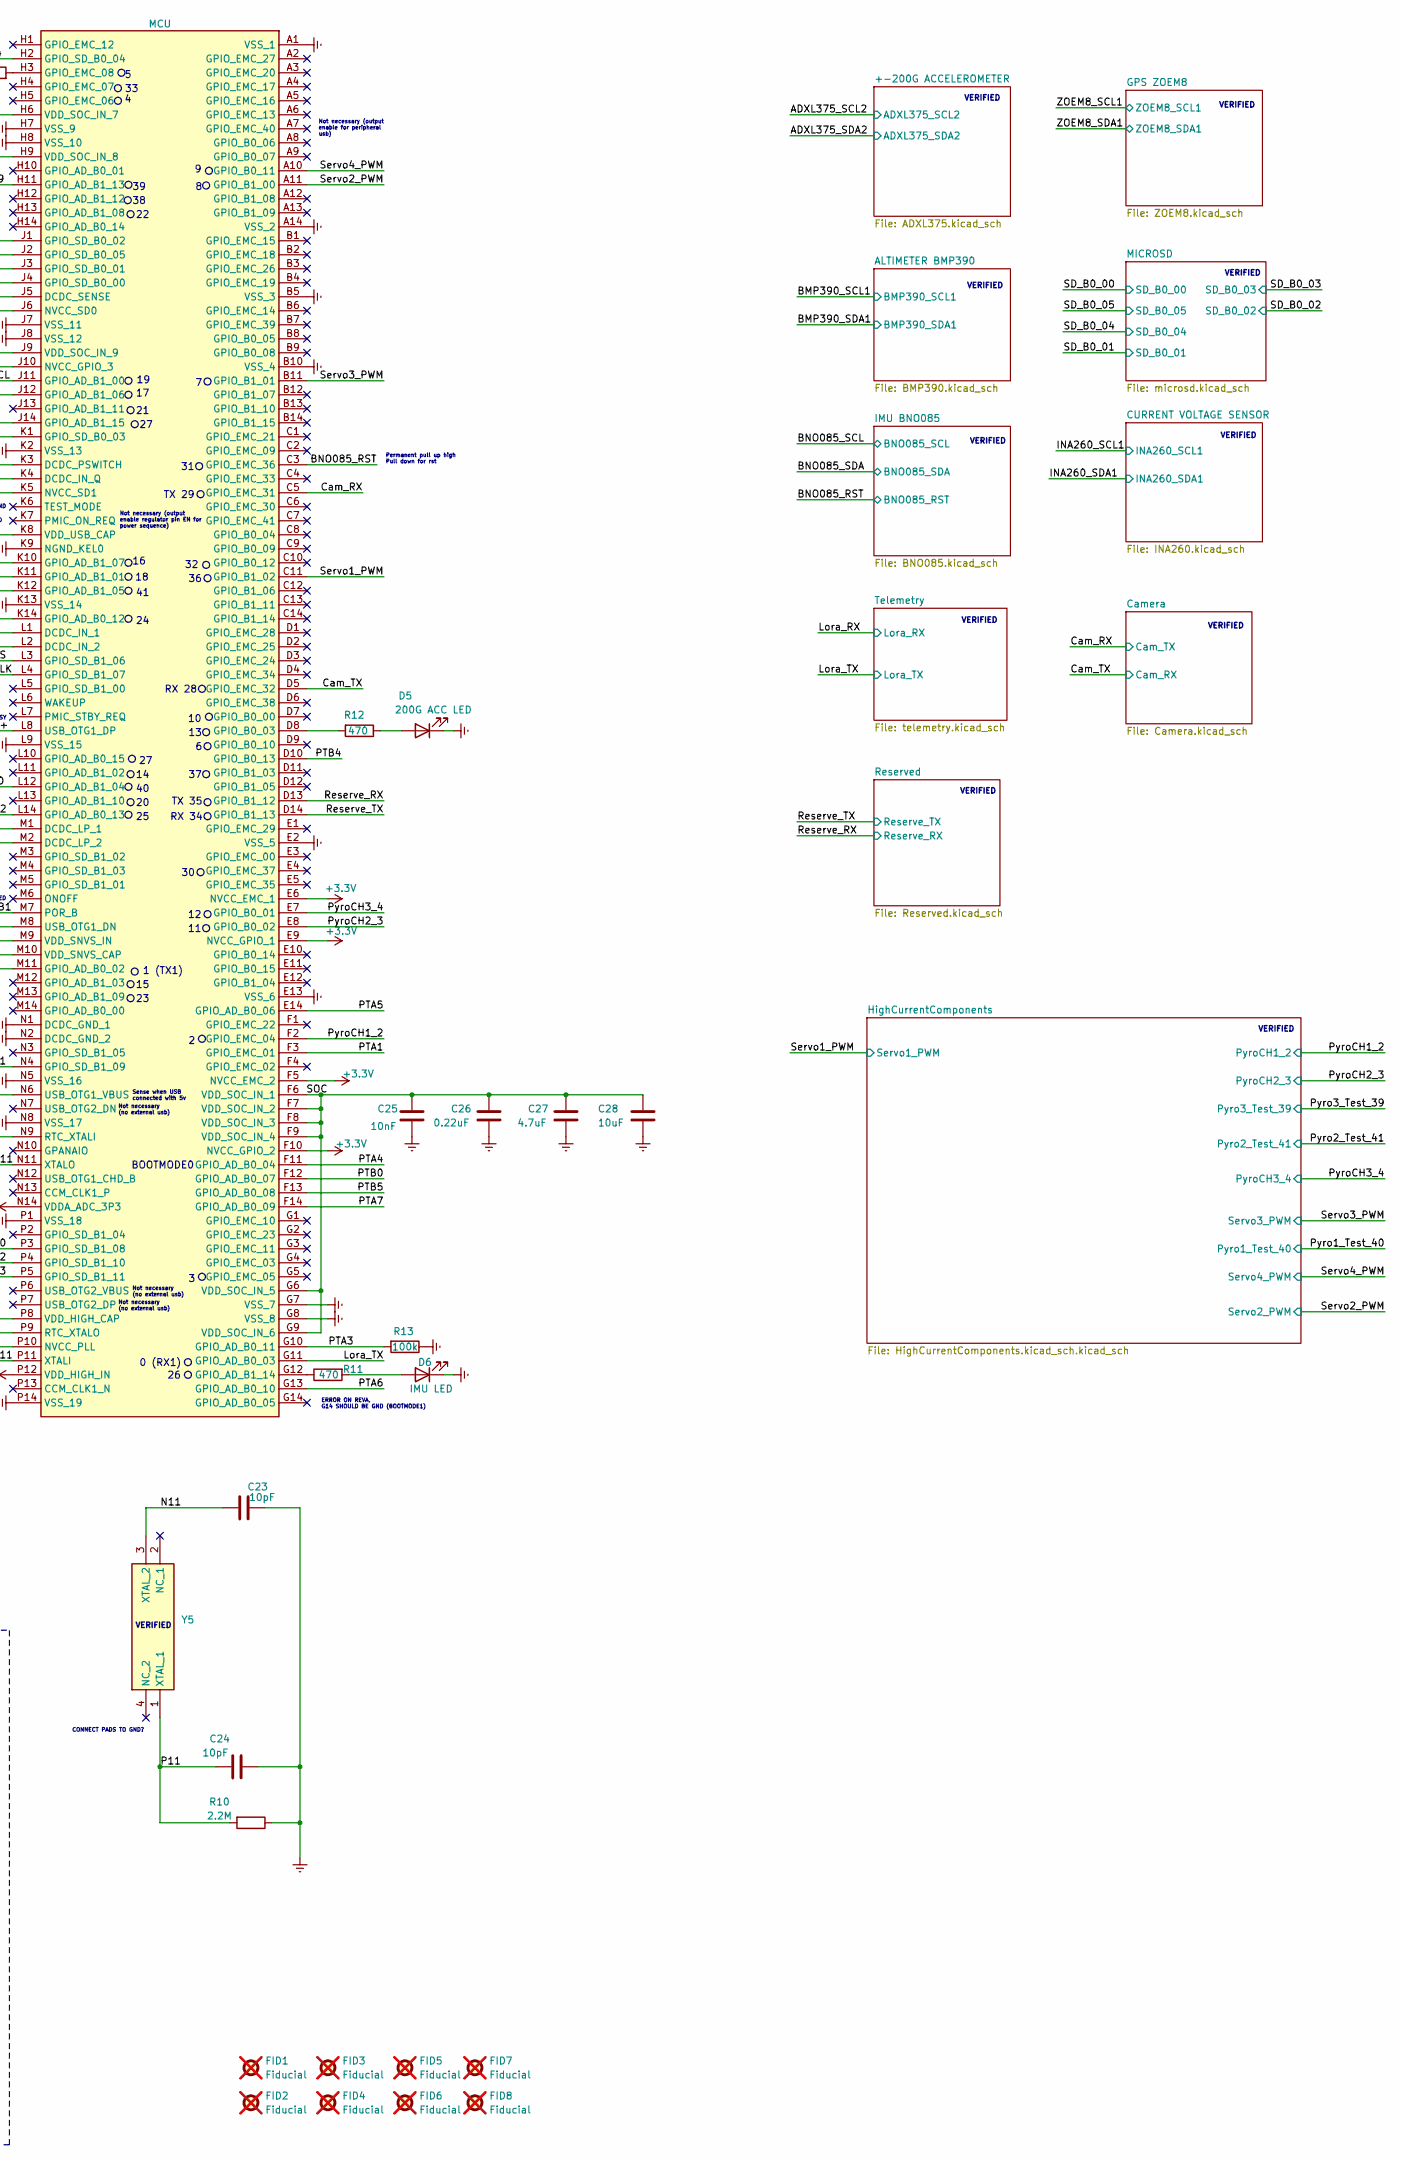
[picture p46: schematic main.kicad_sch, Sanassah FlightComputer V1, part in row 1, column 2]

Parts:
C1: 10uF; R_0603_1608Metric_Pad0.98x0.95mm_HandSolder; Rating 25V; LCSC C70225
C2: 22uF; R_0603_1608Metric_Pad0.98x0.95mm_HandSolder; Rating 6.3V; LCSC C2762594
C3: 1uF; R_0603_1608Metric_Pad0.98x0.95mm_HandSolder; LCSC C1592
C5, C12, C13, C18, C19, C20, C21, C22, C26: 0.22uF; R_0603_1608Metric_Pad0.98x0.95mm_HandSolder; LCSC C106216
C6: 2.2uF; R_0603_1608Metric_Pad0.98x0.95mm_HandSolder; LCSC C23630
C7, C11, C28: 10uF; R_0603_1608Metric_Pad0.98x0.95mm_HandSolder; LCSC C70225
C8, C14, C15, C16, C27: 4.7uF; R_0603_1608Metric_Pad0.98x0.95mm_HandSolder; LCSC C19666
C9, C10: 18pF; R_0603_1608Metric_Pad0.98x0.95mm_HandSolder; LCSC C1647
C17, C25: 10nF; R_0603_1608Metric_Pad0.98x0.95mm_HandSolder; LCSC C149619
C23, C24: 10pF; R_0603_1608Metric_Pad0.98x0.95mm_HandSolder; LCSC C2168929
D1: 3.3V LED; LED_0603_1608Metric_Pad1.05x0.95mm_HandSolder; Mouser Part Number 78-TLMG1100-GS15; LCSC C20433785
D2: BOOT LED; LED_0603_1608Metric_Pad1.05x0.95mm_HandSolder; Mouser Part Number 78-TLMG1100-GS15; LCSC C20433785
D3: GPS LED; LED_0603_1608Metric_Pad1.05x0.95mm_HandSolder; Mouser Part Number 78-TLMG1100-GS15; LCSC C20433785
D4: Altimeter LED; LED_0603_1608Metric_Pad1.05x0.95mm_HandSolder; Mouser Part Number 78-TLMG1100-GS15; LCSC C20433785
D5: 200G ACC LED; LED_0603_1608Metric_Pad1.05x0.95mm_HandSolder; Mouser Part Number 78-TLMG1100-GS15; LCSC C20433785
D6: IMU LED; LED_0603_1608Metric_Pad1.05x0.95mm_HandSolder; Mouser Part Number 78-TLMG1100-GS15; LCSC C20433785
FB1, FB2: 120; R_0603_1608Metric_Pad0.98x0.95mm_HandSolder; Mouser Part Number 81-BLM18PG121SN1D; LCSC C14709
FID1, FID2, FID3, FID4, FID5, FID6, FID7, FID8: Fiducial; Fiducial_1mm_Mask2mm; not fitted
FLASH1: GD25Q64ESIG; Mouser Part Number 363-GD25Q64ESIG
KMR241GLFS1: RESET; KMR421GULCLFS; Mouser Part Number 611-KMR241GLFS
L1: 6.8uH; L_1008_2520Metric_Pad1.43x2.20mm_HandSolder; Mouser Part Number 810-VLS25212HBX6R8M1; LCSC C307868
L2: 4.7uH; L_0805_2012Metric_Pad1.05x1.20mm_HandSolder; Mouser Part Number 81-LQM21PN4R7NGRDRD; LCSC C397305
MIMXRT1062DVL6B1: MCU; BGA196C80P14X14_1200X1200X152; Manufacturer_Part_Number MIMXRT1062DVL6B; Mouser Part Number 771-MIMXRT1062DVL6B
MKL02Z32VFG1: BOOT; QFN50P300X300X65-17N-D; Manufacturer_Part_Number MKL02Z32VFG4
R1, R2: 5.1k; R_0603_1608Metric_Pad0.98x0.95mm_HandSolder; LCSC C22356467
R3: 1M; R_0603_1608Metric_Pad0.98x0.95mm_HandSolder; LCSC C22935
R4, R5, R7, R9, R11, R12: 470; R_0603_1608Metric_Pad0.98x0.95mm_HandSolder; LCSC C23179
R6, R8: 4.7k; R_0603_1608Metric_Pad0.98x0.95mm_HandSolder; LCSC C23162
R10: 2.2M; R_0603_1608Metric_Pad0.98x0.95mm_HandSolder; LCSC C18679
R13: 100k; R_0603_1608Metric_Pad0.98x0.95mm_HandSolder; LCSC C14675
TPS62111RSAR1: 3.3Vreg; TPS62111RSAR; Mouser Part Number 595-TPS62111RSAR
USB_C_Receptacle_USB2.0_14P1: USBc; USB_C_Receptacle_GCT_USB4110; Mouser Part Number 640-USB4110-GF-A; LCSC C5143397
Y1: 32.768kHz; Crystal_SMD_2012-2Pin_2.0x1.2mm_HandSoldering; Mouser Part Number 815-ABS06-32.7K-9-T; LCSC C510776
Y5: XRCGB24M000F2P29R0; XRCGB; Mouser Part Number 81-XRCGB24M000F2P29R

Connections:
+3.3V: C2.2, C5.1, C6.1, C8.1, C13.1, C17.1, C19.1, D1.2 (A), D2.2 (A), FB2.1, FLASH1.8 (VCC), L1.2, MIMXRT1062DVL6B1.E6 (NVCC_EMC_1), MIMXRT1062DVL6B1.E9 (NVCC_GPIO_1), MIMXRT1062DVL6B1.F5 (NVCC_EMC_2), MIMXRT1062DVL6B1.F10 (NVCC_GPIO_2), MIMXRT1062DVL6B1.J6 (NVCC_SD0), MIMXRT1062DVL6B1.J10 (NVCC_GPIO_3), MIMXRT1062DVL6B1.K4 (DCDC_IN_Q), MIMXRT1062DVL6B1.K5 (NVCC_SD1), MIMXRT1062DVL6B1.M9 (VDD_SNVS_IN), MIMXRT1062DVL6B1.N14 (VDDA_ADC_3P3), MIMXRT1062DVL6B1.P12 (VDD_HIGH_IN), MKL02Z32VFG1.1 (VDD_VREFH), R3.2, R6.2, R8.1, TPS62111RSAR1.10 (FB); also elsewhere on the board
+7.5V: C1.1, C3.2, TPS62111RSAR1.2 (VIN_1), TPS62111RSAR1.3 (VIN_2), TPS62111RSAR1.4 (EN), TPS62111RSAR1.8 (VINA); also elsewhere on the board
/ADXL375_SCL2: MIMXRT1062DVL6B1.K14 (GPIO_AD_B0_12); also elsewhere on the board
/ADXL375_SDA2: MIMXRT1062DVL6B1.L14 (GPIO_AD_B0_13); also elsewhere on the board
/BMP390_SCL1: MIMXRT1062DVL6B1.K10 (GPIO_AD_B1_07), R8.2; also elsewhere on the board
/BMP390_SDA1: MIMXRT1062DVL6B1.J12 (GPIO_AD_B1_06), R6.1; also elsewhere on the board
/BNO085_RST: MIMXRT1062DVL6B1.C3 (GPIO_EMC_36); also elsewhere on the board
/BNO085_SCL: MIMXRT1062DVL6B1.J11 (GPIO_AD_B1_00); also elsewhere on the board
/BNO085_SDA: MIMXRT1062DVL6B1.K11 (GPIO_AD_B1_01); also elsewhere on the board
/CLK: FLASH1.6 (SCLK), MIMXRT1062DVL6B1.L4 (GPIO_SD_B1_07)
/CS: FLASH1.1 (CS#), MIMXRT1062DVL6B1.L3 (GPIO_SD_B1_06)
/Cam_RX: MIMXRT1062DVL6B1.C5 (GPIO_EMC_31); also elsewhere on the board
/Cam_TX: MIMXRT1062DVL6B1.D5 (GPIO_EMC_32); also elsewhere on the board
/D0: FLASH1.5 (SI_(IO0)), MIMXRT1062DVL6B1.P3 (GPIO_SD_B1_08)
/D1: FLASH1.2 (SO_(IO1)), MIMXRT1062DVL6B1.N4 (GPIO_SD_B1_09)
/D2: FLASH1.3 (WP#_(IO2)), MIMXRT1062DVL6B1.P4 (GPIO_SD_B1_10)
/D3: FLASH1.7 (HOLD#_(IO3)), MIMXRT1062DVL6B1.P5 (GPIO_SD_B1_11)
/D+: MIMXRT1062DVL6B1.L8 (USB_OTG1_DP), USB_C_Receptacle_USB2.0_14P1.A6 (D+), USB_C_Receptacle_USB2.0_14P1.B6 (D+)
/D-: MIMXRT1062DVL6B1.M8 (USB_OTG1_DN), USB_C_Receptacle_USB2.0_14P1.A7 (D-), USB_C_Receptacle_USB2.0_14P1.B7 (D-)
/Lora_RX: MIMXRT1062DVL6B1.M11 (GPIO_AD_B0_02); also elsewhere on the board
/Lora_TX: MIMXRT1062DVL6B1.G11 (GPIO_AD_B0_03); also elsewhere on the board
/N11: C23.1, MIMXRT1062DVL6B1.N11 (XTALO), Y5.3 (XTAL_2)
/P11: C24.2, MIMXRT1062DVL6B1.P11 (XTALI), R10.2, Y5.1 (XTAL_1)
/PTA1: MIMXRT1062DVL6B1.F3 (GPIO_EMC_01), MKL02Z32VFG1.15 (PTA1/IRQ_1/LPTMR0_ALT1)
/PTA3: MIMXRT1062DVL6B1.G10 (GPIO_AD_B0_11), MIMXRT1062DVL6B1.K3 (DCDC_PSWITCH), MKL02Z32VFG1.3 (PTA3), R13.2
/PTA4: MIMXRT1062DVL6B1.F11 (GPIO_AD_B0_04), MKL02Z32VFG1.4 (PTA4)
/PTA5: MIMXRT1062DVL6B1.E14 (GPIO_AD_B0_06), MKL02Z32VFG1.5 (PTA5)
/PTA6: MIMXRT1062DVL6B1.G13 (GPIO_AD_B0_10), MKL02Z32VFG1.6 (PTA6)
/PTA7: MIMXRT1062DVL6B1.F14 (GPIO_AD_B0_09), MKL02Z32VFG1.7 (PTA7/IRQ_4)
/PTB0: MIMXRT1062DVL6B1.F12 (GPIO_AD_B0_07), MKL02Z32VFG1.8 (PTB0/IRQ_5)
/PTB1: MIMXRT1062DVL6B1.M7 (POR_B), MKL02Z32VFG1.9 (PTB1/IRQ_6)
/PTB4: MIMXRT1062DVL6B1.D10 (GPIO_B0_13), MKL02Z32VFG1.12 (PTB4/IRQ_11)
/PTB5: MIMXRT1062DVL6B1.F13 (GPIO_AD_B0_08), MKL02Z32VFG1.13 (PTB5/IRQ_12)
/Pyro1_Test_40: MIMXRT1062DVL6B1.L12 (GPIO_AD_B1_04); also elsewhere on the board
/Pyro2_Test_41: MIMXRT1062DVL6B1.K12 (GPIO_AD_B1_05); also elsewhere on the board
/Pyro3_Test_39: MIMXRT1062DVL6B1.H11 (GPIO_AD_B1_13); also elsewhere on the board
/PyroCH1_2: MIMXRT1062DVL6B1.F2 (GPIO_EMC_04); also elsewhere on the board
/PyroCH2_3: MIMXRT1062DVL6B1.E8 (GPIO_B0_02); also elsewhere on the board
/PyroCH3_4: MIMXRT1062DVL6B1.E7 (GPIO_B0_01); also elsewhere on the board
/Reserve_RX: MIMXRT1062DVL6B1.D13 (GPIO_B1_12); also elsewhere on the board
/Reserve_TX: MIMXRT1062DVL6B1.D14 (GPIO_B1_13); also elsewhere on the board
/SD_B0_00: MIMXRT1062DVL6B1.J4 (GPIO_SD_B0_00); also elsewhere on the board
/SD_B0_01: MIMXRT1062DVL6B1.J3 (GPIO_SD_B0_01); also elsewhere on the board
/SD_B0_02: MIMXRT1062DVL6B1.J1 (GPIO_SD_B0_02); also elsewhere on the board
/SD_B0_03: MIMXRT1062DVL6B1.K1 (GPIO_SD_B0_03); also elsewhere on the board
/SD_B0_04: MIMXRT1062DVL6B1.H2 (GPIO_SD_B0_04); also elsewhere on the board
/SD_B0_05: MIMXRT1062DVL6B1.J2 (GPIO_SD_B0_05); also elsewhere on the board
/SOC: C25.1, C26.1, C27.1, C28.1, L2.2, MIMXRT1062DVL6B1.F6 (VDD_SOC_IN_1), MIMXRT1062DVL6B1.F7 (VDD_SOC_IN_2), MIMXRT1062DVL6B1.F8 (VDD_SOC_IN_3), MIMXRT1062DVL6B1.F9 (VDD_SOC_IN_4), MIMXRT1062DVL6B1.G6 (VDD_SOC_IN_5), MIMXRT1062DVL6B1.G9 (VDD_SOC_IN_6), MIMXRT1062DVL6B1.H6 (VDD_SOC_IN_7), MIMXRT1062DVL6B1.H9 (VDD_SOC_IN_8), MIMXRT1062DVL6B1.J5 (DCDC_SENSE), MIMXRT1062DVL6B1.J9 (VDD_SOC_IN_9)
/Servo1_PWM: MIMXRT1062DVL6B1.C11 (GPIO_B1_02); also elsewhere on the board
/Servo2_PWM: MIMXRT1062DVL6B1.A11 (GPIO_B1_00); also elsewhere on the board
/Servo3_PWM: MIMXRT1062DVL6B1.B11 (GPIO_B1_01); also elsewhere on the board
/Servo4_PWM: MIMXRT1062DVL6B1.A10 (GPIO_B0_11); also elsewhere on the board
GNDREF: C1.2, C2.1, C3.1, C5.2, C6.2, C7.2, C8.2, C9.2, C10.1, C11.2, C12.2, C13.2, C14.2, C15.2, C16.2, C17.2, C18.2, C19.2, C20.2, C21.2, C22.1, C23.2, C24.1, C25.2, C26.2, C27.2, C28.2, D3.1 (K), D4.1 (K), D5.1 (K), D6.1 (K), FLASH1.4 (VSS), KMR241GLFS1.2 (NO_1), KMR241GLFS1.3 (NO_2), KMR241GLFS1.5 (GND), MIMXRT1062DVL6B1.A1 (VSS_1), MIMXRT1062DVL6B1.A14 (VSS_2), MIMXRT1062DVL6B1.B5 (VSS_3), MIMXRT1062DVL6B1.B10 (VSS_4), MIMXRT1062DVL6B1.E2 (VSS_5), MIMXRT1062DVL6B1.E13 (VSS_6), MIMXRT1062DVL6B1.G7 (VSS_7), MIMXRT1062DVL6B1.G8 (VSS_8), MIMXRT1062DVL6B1.H7 (VSS_9), MIMXRT1062DVL6B1.H8 (VSS_10), MIMXRT1062DVL6B1.J7 (VSS_11), MIMXRT1062DVL6B1.J8 (VSS_12), MIMXRT1062DVL6B1.K2 (VSS_13), MIMXRT1062DVL6B1.K9 (NGND_KEL0), MIMXRT1062DVL6B1.K13 (VSS_14), MIMXRT1062DVL6B1.L9 (VSS_15), MIMXRT1062DVL6B1.N1 (DCDC_GND_1), MIMXRT1062DVL6B1.N2 (DCDC_GND_2), MIMXRT1062DVL6B1.N5 (VSS_16), MIMXRT1062DVL6B1.N8 (VSS_17), MIMXRT1062DVL6B1.P1 (VSS_18), MIMXRT1062DVL6B1.P14 (VSS_19), MKL02Z32VFG1.2 (VREFL_VSS), MKL02Z32VFG1.17 (EP), R1.2, R2.2, R4.1, R10.1, R13.1, TPS62111RSAR1.1 (PGND_1), TPS62111RSAR1.5 (SYNC), TPS62111RSAR1.6 (LBO), TPS62111RSAR1.7 (LBI), TPS62111RSAR1.9 (AGND), TPS62111RSAR1.11 (GND_1), TPS62111RSAR1.12 (GND_2), TPS62111RSAR1.16 (PGND_2), TPS62111RSAR1.17 (EP), USB_C_Receptacle_USB2.0_14P1.A1 (GND), USB_C_Receptacle_USB2.0_14P1.A12 (GND), USB_C_Receptacle_USB2.0_14P1.B1 (GND), USB_C_Receptacle_USB2.0_14P1.B12 (GND), USB_C_Receptacle_USB2.0_14P1.S1 (SHIELD); also elsewhere on the board
unnamed: D1.1 (K), R4.2
unnamed: D2.1 (K), R5.2
unnamed: D3.2 (A), R7.1
unnamed: D4.2 (A), R9.1
unnamed: D5.2 (A), R12.1
unnamed: D6.2 (A), R11.2
unnamed: FB1.1, USB_C_Receptacle_USB2.0_14P1.A4 (VBUS), USB_C_Receptacle_USB2.0_14P1.A9 (VBUS), USB_C_Receptacle_USB2.0_14P1.B4 (VBUS), USB_C_Receptacle_USB2.0_14P1.B9 (VBUS)
unnamed: KMR241GLFS1.1 (COM_1), MKL02Z32VFG1.10 (PTB2/IRQ_7)
unnamed: C11.1, C14.1, C18.1, FB2.2, MIMXRT1062DVL6B1.L1 (DCDC_IN_1), MIMXRT1062DVL6B1.L2 (DCDC_IN_2)
unnamed: L2.1, MIMXRT1062DVL6B1.M1 (DCDC_LP_1), MIMXRT1062DVL6B1.M2 (DCDC_LP_2)
unnamed: MIMXRT1062DVL6B1.G12 (GPIO_AD_B1_14), R11.1
unnamed: MIMXRT1062DVL6B1.J14 (GPIO_AD_B1_15), R7.2
unnamed: MIMXRT1062DVL6B1.D8 (GPIO_B0_03), R12.2
unnamed: MIMXRT1062DVL6B1.H3 (GPIO_EMC_08), R9.2
unnamed: C16.1, C21.1, MIMXRT1062DVL6B1.P10 (NVCC_PLL)
unnamed: C9.1, MIMXRT1062DVL6B1.N9 (RTC_XTALI), Y1.2
unnamed: C10.2, MIMXRT1062DVL6B1.P9 (RTC_XTALO), Y1.1
unnamed: FB1.2, MIMXRT1062DVL6B1.N6 (USB_OTG1_VBUS)
unnamed: C15.1, C20.1, MIMXRT1062DVL6B1.P8 (VDD_HIGH_CAP)
unnamed: C22.2, MIMXRT1062DVL6B1.M10 (VDD_SNVS_CAP)
unnamed: C7.1, C12.1, MIMXRT1062DVL6B1.K8 (VDD_USB_CAP)
unnamed: MKL02Z32VFG1.11 (PTB3/IRQ_10), R5.1
unnamed: R3.1, TPS62111RSAR1.13 (PG)
unnamed: L1.1, TPS62111RSAR1.14 (SW_1), TPS62111RSAR1.15 (SW_2)
unnamed: R1.1, USB_C_Receptacle_USB2.0_14P1.A5 (CC1)
unnamed: R2.1, USB_C_Receptacle_USB2.0_14P1.B5 (CC2)

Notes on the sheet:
VERIFIED
0 (RX1)
2.55ma to LED
Not necessary (no external usb)
Batt(17V to 3.3V) to 3.3V regulator (max 1.5A)
Not necessary (output enable regulator pin EN for power sequence)
Not necessary (output enable for peripheral usb)
TX 29
L7 NOT CONNECTED ON TEENSY
NO CONNECTION NEEDED
ERROR ON REVA, K6 NEEDS TO BE GND
1 (TX1)
TX 35
CONNECT PADS TO GND?
Permanent pull up high Pull down for rst
RX 34
ERROR ON REVA, G14 SHOULD BE GND (BOOTMODE1)
Sense when USB connected with 5v
Fixed 3.3v output version
BOOTMODE0
NOT NEEDED
Bootloader
RX 28

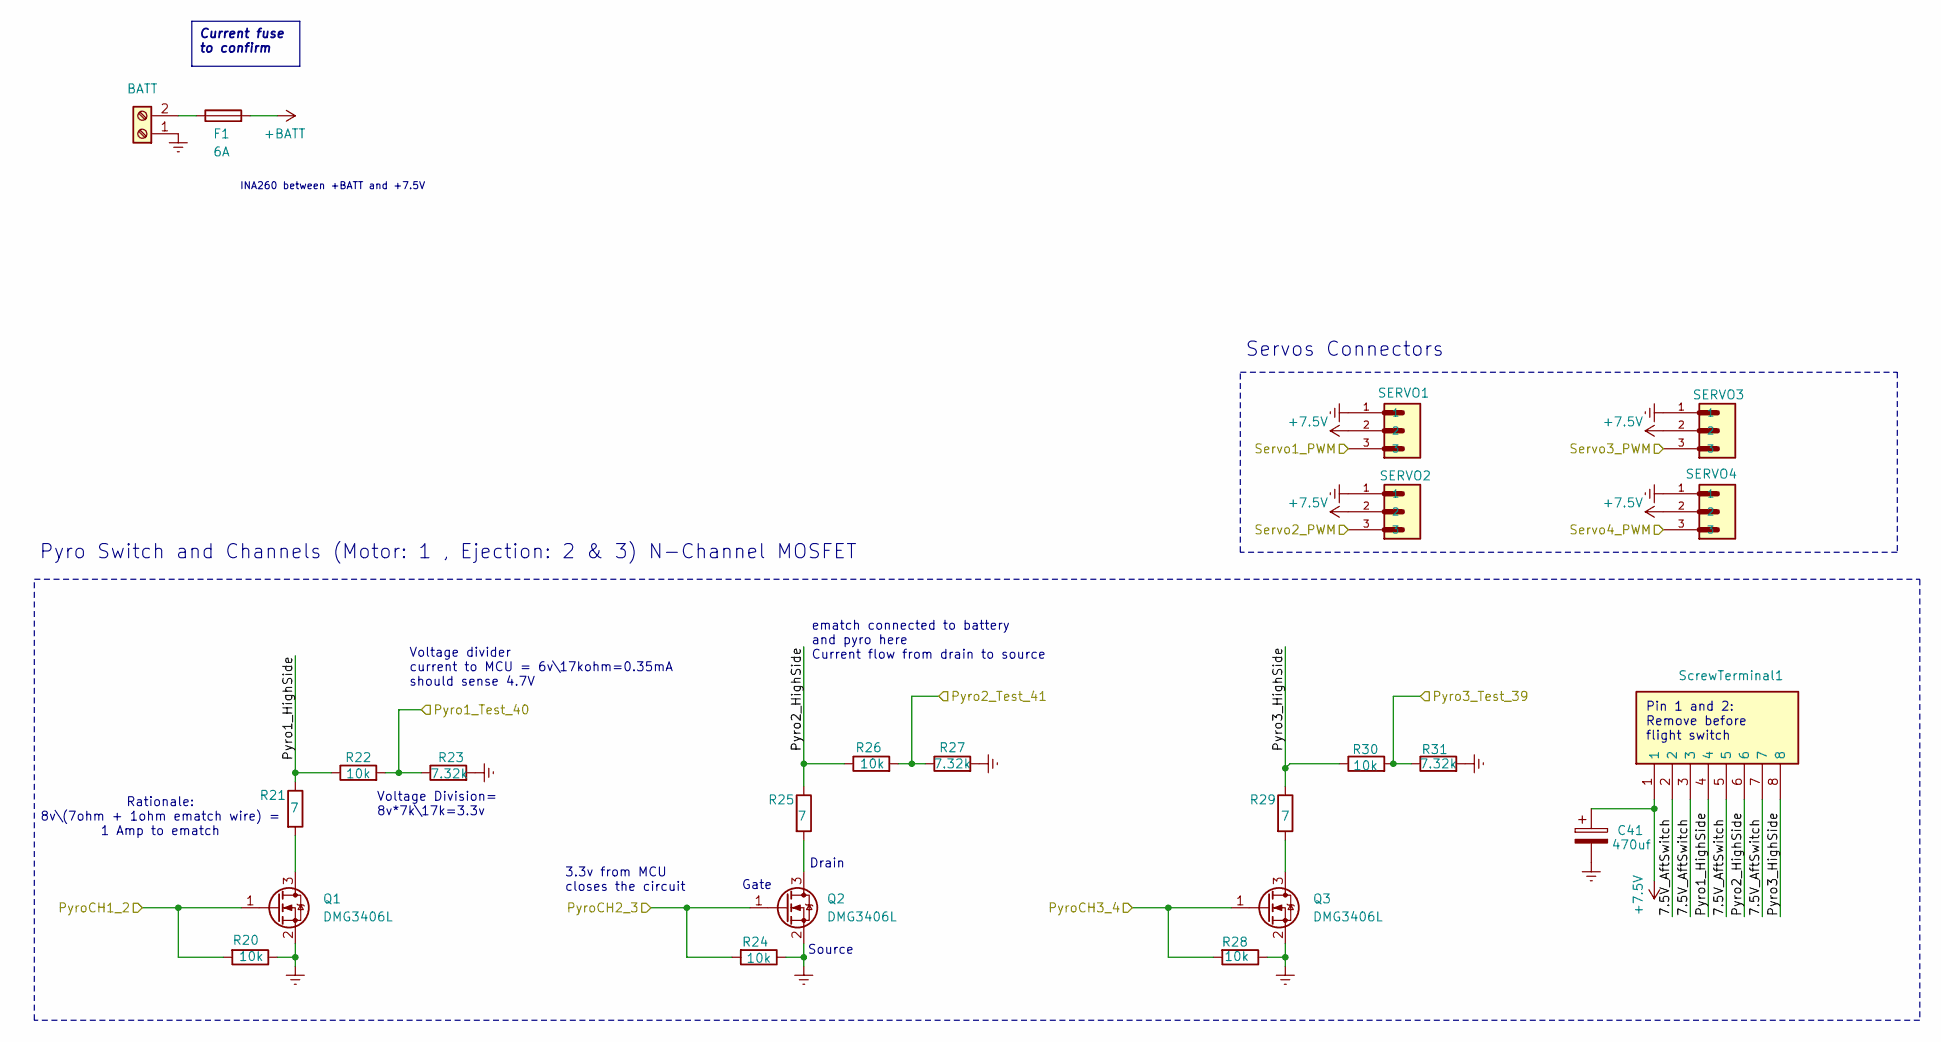
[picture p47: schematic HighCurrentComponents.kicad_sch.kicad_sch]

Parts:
C41: 470uf; C_Radial_D6.3mm_H11.0mm_P2.50mm; LCSC C1020067
F1: 6A; Fuse_1206_3216Metric; Mouser Part Number 530-C1F6; LCSC C183157
Q1, Q2, Q3: DMG3406L; SOT-23; Mouser Part Number 621-DMG3406L-7; LCSC C460978
R20, R22, R24, R26, R28, R30: 10k; R_0603_1608Metric_Pad0.98x0.95mm_HandSolder; LCSC C25804
R21, R25, R29: 7; R_0603_1608Metric_Pad0.98x0.95mm_HandSolder; LCSC C228062
R23, R27, R31: 7.32k; R_0603_1608Metric_Pad0.98x0.95mm_HandSolder; LCSC C23101
SERVO1: SERVO1; JST_GH_BM03B-GHS-TBT_1x03-1MP_P1.25mm_Vertical; Mouser Part Number 306-BM03BGHSTBTLFSNN; LCSC C161691
SERVO2: SERVO2; JST_GH_BM03B-GHS-TBT_1x03-1MP_P1.25mm_Vertical; Mouser Part Number 306-BM03BGHSTBTLFSNN; LCSC C161691
SERVO3: SERVO3; JST_GH_BM03B-GHS-TBT_1x03-1MP_P1.25mm_Vertical; Mouser Part Number 306-BM03BGHSTBTLFSNN; LCSC C161691
SERVO4: SERVO4; JST_GH_BM03B-GHS-TBT_1x03-1MP_P1.25mm_Vertical; Mouser Part Number 306-BM03BGHSTBTLFSNN; LCSC C161691
ScrewTerminal1: 1725711; Mouser Part Number 651-1725711
ScrewTerminal2: BATT; 1725656; Mouser Part Number 651-1725656; LCSC C3029316

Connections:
+7.5V: C41.1, SERVO1.2, SERVO2.2, SERVO3.2, SERVO4.2, ScrewTerminal1.1; also elsewhere on the board
+BATT: F1.2; also elsewhere on the board
/HighCurrentComponents/7.5V_AftSwitch: ScrewTerminal1.2, ScrewTerminal1.3, ScrewTerminal1.5, ScrewTerminal1.7
/HighCurrentComponents/Pyro1_HighSide: R21.1, R22.1, ScrewTerminal1.4
/HighCurrentComponents/Pyro2_HighSide: R25.1, R26.1, ScrewTerminal1.6
/HighCurrentComponents/Pyro3_HighSide: R29.1, R30.1, ScrewTerminal1.8
/Pyro1_Test_40: R22.2, R23.1; also elsewhere on the board
/Pyro2_Test_41: R26.2, R27.1; also elsewhere on the board
/Pyro3_Test_39: R30.2, R31.1; also elsewhere on the board
/PyroCH1_2: Q1.1 (G), R20.2; also elsewhere on the board
/PyroCH2_3: Q2.1 (G), R24.2; also elsewhere on the board
/PyroCH3_4: Q3.1 (G), R28.2; also elsewhere on the board
/Servo1_PWM: SERVO1.3; also elsewhere on the board
/Servo2_PWM: SERVO2.3; also elsewhere on the board
/Servo3_PWM: SERVO3.3; also elsewhere on the board
/Servo4_PWM: SERVO4.3; also elsewhere on the board
GNDREF: C41.2, Q1.2 (S), Q2.2 (S), Q3.2 (S), R20.1, R23.2, R24.1, R27.2, R28.1, R31.2, SERVO1.1, SERVO2.1, SERVO3.1, SERVO4.1, ScrewTerminal2.1; also elsewhere on the board
unnamed: Q1.3 (D), R21.2
unnamed: Q2.3 (D), R25.2
unnamed: Q3.3 (D), R29.2
unnamed: F1.1, ScrewTerminal2.2

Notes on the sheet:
Voltage Division= 8v*7k\17k=3.3v
INA260 between +BATT and +7.5V
Source
Servos Connectors
Voltage divider current to MCU = 6v\17kohm=0.35mA should sense 4.7V
Pin 1 and 2: Remove before flight switch
Drain
Pyro Switch and Channels (Motor: 1 , Ejection: 2 & 3) N-Channel MOSFET
Rationale: 8v\(7ohm + 1ohm ematch wire) = 1 Amp to ematch
ematch connected to battery and pyro here Current flow from drain to source
Gate
3.3v from MCU closes the circuit
Current fuse to confirm

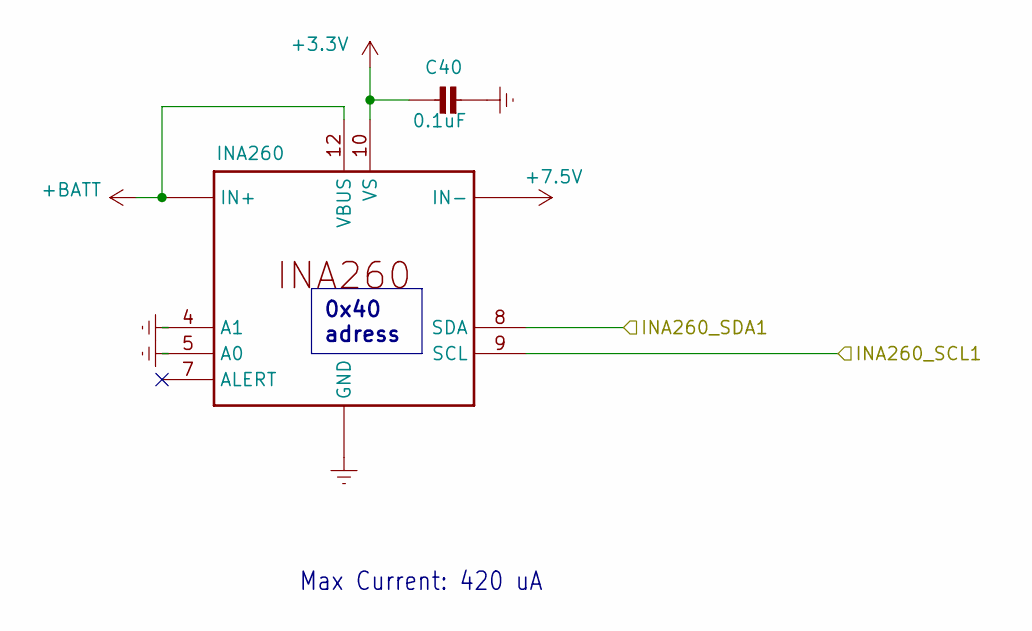
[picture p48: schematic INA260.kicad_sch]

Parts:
C40: 0.1uF; R_0603_1608Metric_Pad0.98x0.95mm_HandSolder; LCSC C1590
INA1: INA260; TSSOP16; Mouser Part Number 595-INA260AIPWR; LCSC C2155885

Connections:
+3.3V: C40.1, INA1.10 (VS); also elsewhere on the board
+7.5V: INA1.14 (IN-), INA1.15 (IN-), INA1.16 (IN-); also elsewhere on the board
+BATT: INA1.1 (IN+), INA1.2 (IN+), INA1.3 (IN+), INA1.12 (VBUS); also elsewhere on the board
/BMP390_SCL1: INA1.9 (SCL); also elsewhere on the board
/BMP390_SDA1: INA1.8 (SDA); also elsewhere on the board
GNDREF: C40.2, INA1.4 (A1), INA1.5 (A0), INA1.6 (GND), INA1.11 (GND), INA1.13 (GND); also elsewhere on the board

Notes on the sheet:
Max Current: 420 uA
0x40 adress

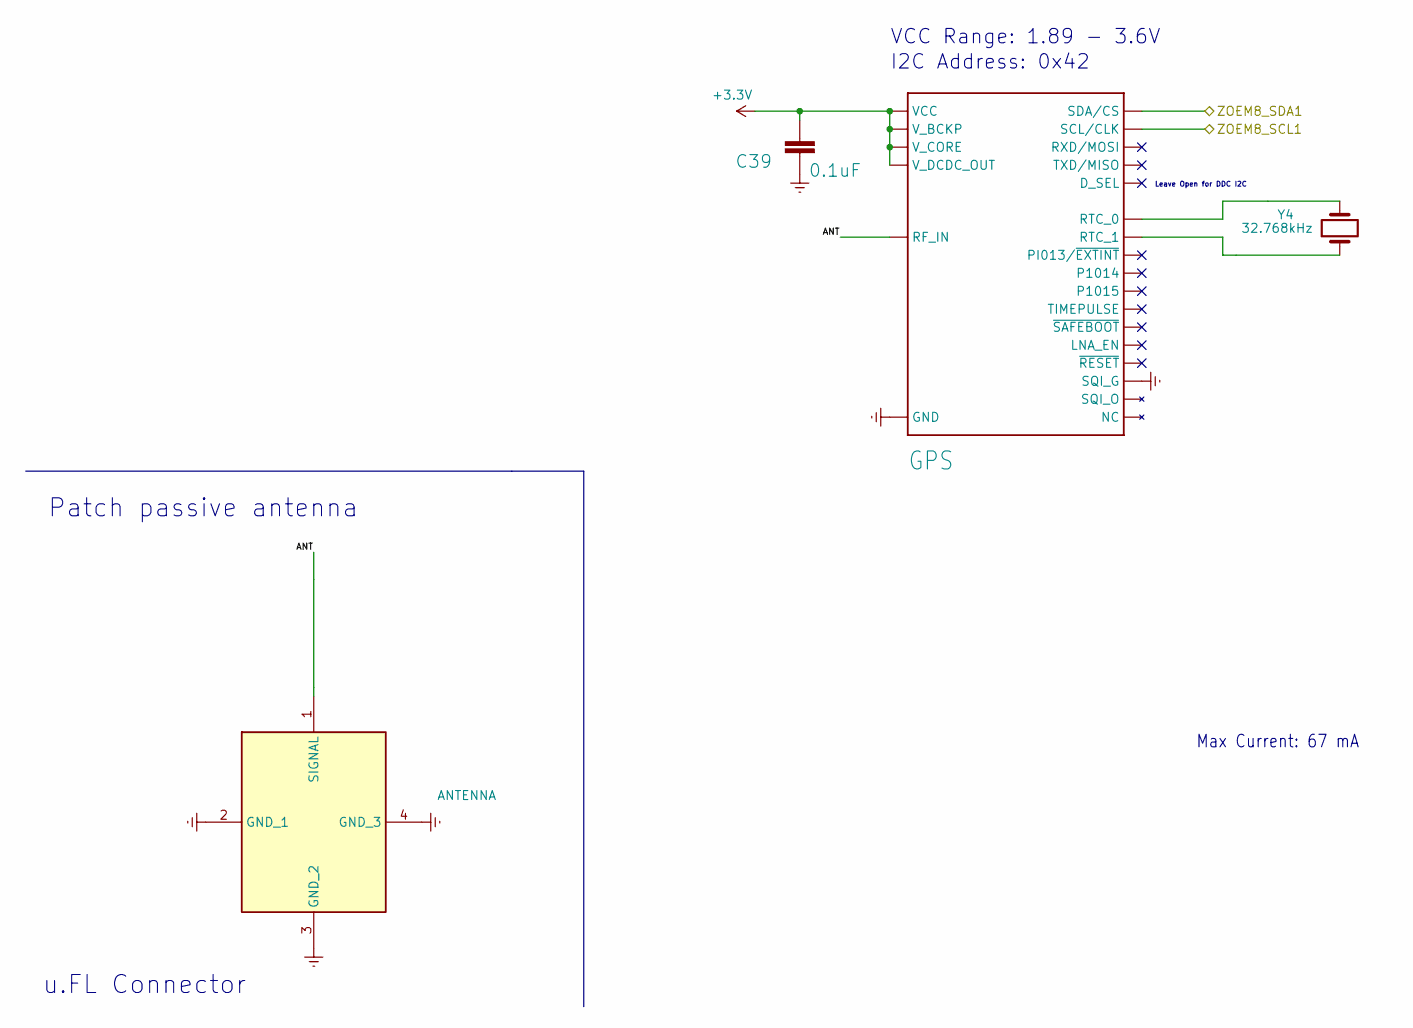
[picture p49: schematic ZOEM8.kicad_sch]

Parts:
C39: 0.1uF; R_0603_1608Metric_Pad0.98x0.95mm_HandSolder; LCSC C1590
CONMHF1-SMD-G-T1: ANTENNA; CONMHF1SMDGT; Mouser Part Number 712-CONMHF1-SMD-G-T
U-BLOX_ZOE_M8Q-0-1: GPS; UBLOX_ZOE_M8-0-10; Mouser Part Number 377-ZOE-M8Q-0
Y4: 32.768kHz; 830050789; Mouser Part Number 428-202816-MC01; LCSC C7462219

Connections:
+3.3V: C39.1, U-BLOX_ZOE_M8Q-0-1.16 (V_BCKP), U-BLOX_ZOE_M8Q-0-1.24 (VCC), U-BLOX_ZOE_M8Q-0-1.25 (VCC), U-BLOX_ZOE_M8Q-0-1.26 (V_DCDC_OUT), U-BLOX_ZOE_M8Q-0-1.27 (V_CORE); also elsewhere on the board
/BMP390_SCL1: U-BLOX_ZOE_M8Q-0-1.32 (SCL/CLK); also elsewhere on the board
/BMP390_SDA1: U-BLOX_ZOE_M8Q-0-1.2 (SDA/CS); also elsewhere on the board
/GPS ZOEM8/ANT: CONMHF1-SMD-G-T1.1 (SIGNAL), U-BLOX_ZOE_M8Q-0-1.4 (RF_IN)
GNDREF: C39.2, CONMHF1-SMD-G-T1.2 (GND_1), CONMHF1-SMD-G-T1.3 (GND_2), CONMHF1-SMD-G-T1.4 (GND_3), U-BLOX_ZOE_M8Q-0-1.1 (GND), U-BLOX_ZOE_M8Q-0-1.3 (GND), U-BLOX_ZOE_M8Q-0-1.5 (GND), U-BLOX_ZOE_M8Q-0-1.7 (GND), U-BLOX_ZOE_M8Q-0-1.8 (GND), U-BLOX_ZOE_M8Q-0-1.9 (GND), U-BLOX_ZOE_M8Q-0-1.10 (GND), U-BLOX_ZOE_M8Q-0-1.11 (GND), U-BLOX_ZOE_M8Q-0-1.12 (GND), U-BLOX_ZOE_M8Q-0-1.17 (GND), U-BLOX_ZOE_M8Q-0-1.23 (GND), U-BLOX_ZOE_M8Q-0-1.29 (SQI_G), U-BLOX_ZOE_M8Q-0-1.31 (SQI_G), U-BLOX_ZOE_M8Q-0-1.37 (GND), U-BLOX_ZOE_M8Q-0-1.38 (GND), U-BLOX_ZOE_M8Q-0-1.39 (GND), U-BLOX_ZOE_M8Q-0-1.40 (GND), U-BLOX_ZOE_M8Q-0-1.41 (GND), U-BLOX_ZOE_M8Q-0-1.44 (GND), U-BLOX_ZOE_M8Q-0-1.46 (SQI_G), U-BLOX_ZOE_M8Q-0-1.47 (SQI_G), U-BLOX_ZOE_M8Q-0-1.49 (GND); also elsewhere on the board
unnamed: U-BLOX_ZOE_M8Q-0-1.18 (RTC_0), Y4.2
unnamed: U-BLOX_ZOE_M8Q-0-1.19 (RTC_1), Y4.1

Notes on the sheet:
I2C Address: 0x42
VCC Range: 1.89 - 3.6V
Max Current: 67 mA
u.FL Connector
Patch passive antenna
Leave Open for DDC I2C

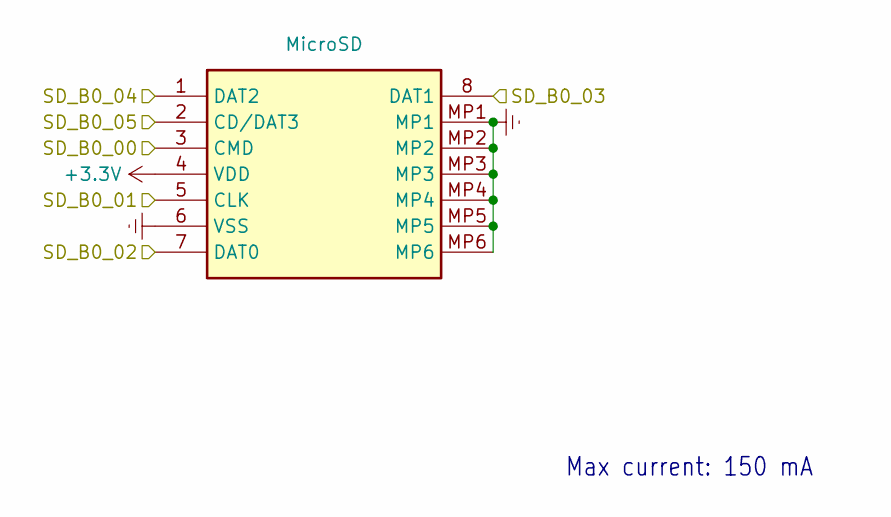
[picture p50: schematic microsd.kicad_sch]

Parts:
DM3D-SF1: MicroSD; DM3DSF; Mouser Part Number 798-DM3D-SF

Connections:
+3.3V: DM3D-SF1.4 (VDD); also elsewhere on the board
/SD_B0_00: DM3D-SF1.3 (CMD); also elsewhere on the board
/SD_B0_01: DM3D-SF1.5 (CLK); also elsewhere on the board
/SD_B0_02: DM3D-SF1.7 (DAT0); also elsewhere on the board
/SD_B0_03: DM3D-SF1.8 (DAT1); also elsewhere on the board
/SD_B0_04: DM3D-SF1.1 (DAT2); also elsewhere on the board
/SD_B0_05: DM3D-SF1.2 (CD/DAT3); also elsewhere on the board
GNDREF: DM3D-SF1.6 (VSS), DM3D-SF1.MP1, DM3D-SF1.MP2, DM3D-SF1.MP3, DM3D-SF1.MP4, DM3D-SF1.MP5, DM3D-SF1.MP6; also elsewhere on the board

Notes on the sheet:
Max current: 150 mA

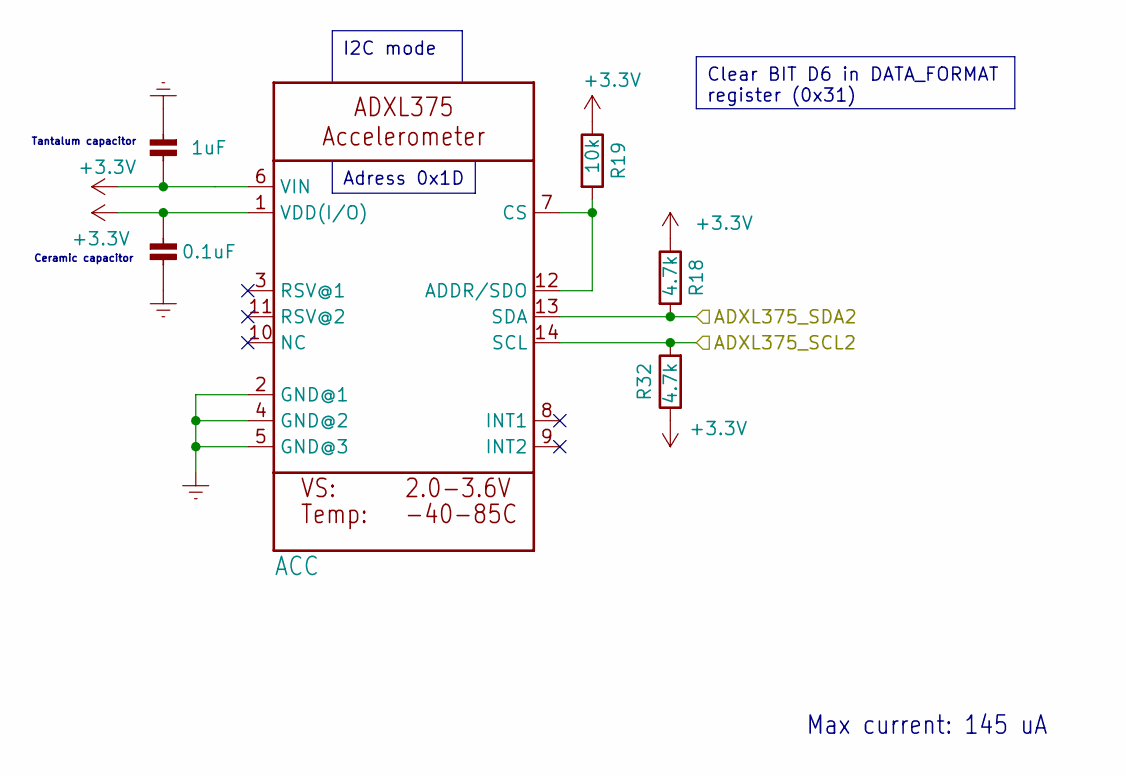
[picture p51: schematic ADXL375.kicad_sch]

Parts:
ADXL1: ACC; ADXL375BCCZRL; Mouser Part Number 584-ADXL375BCCZ; LCSC C579466
C36: 1uF; R_0603_1608Metric_Pad0.98x0.95mm_HandSolder; LCSC C1592
C37: 0.1uF; R_0603_1608Metric_Pad0.98x0.95mm_HandSolder; LCSC C1590
R18, R32: 4.7k; R_0603_1608Metric_Pad0.98x0.95mm_HandSolder; LCSC C23162
R19: 10k; R_0603_1608Metric_Pad0.98x0.95mm_HandSolder; LCSC C25804

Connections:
+3.3V: ADXL1.1 (VDD(I/O)), ADXL1.6 (VIN), C36.1, C37.1, R18.1, R19.1, R32.1; also elsewhere on the board
/ADXL375_SCL2: ADXL1.14 (SCL), R32.2; also elsewhere on the board
/ADXL375_SDA2: ADXL1.13 (SDA), R18.2; also elsewhere on the board
GNDREF: ADXL1.2 (GND@1), ADXL1.4 (GND@2), ADXL1.5 (GND@3), C36.2, C37.2; also elsewhere on the board
unnamed: ADXL1.7 (CS), ADXL1.12 (ADDR/SDO), R19.2

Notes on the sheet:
Tantalum capacitor
Max current: 145 uA
Ceramic capacitor
Clear BIT D6 in DATA_FORMAT register (0x31)
Adress 0x1D
I2C mode

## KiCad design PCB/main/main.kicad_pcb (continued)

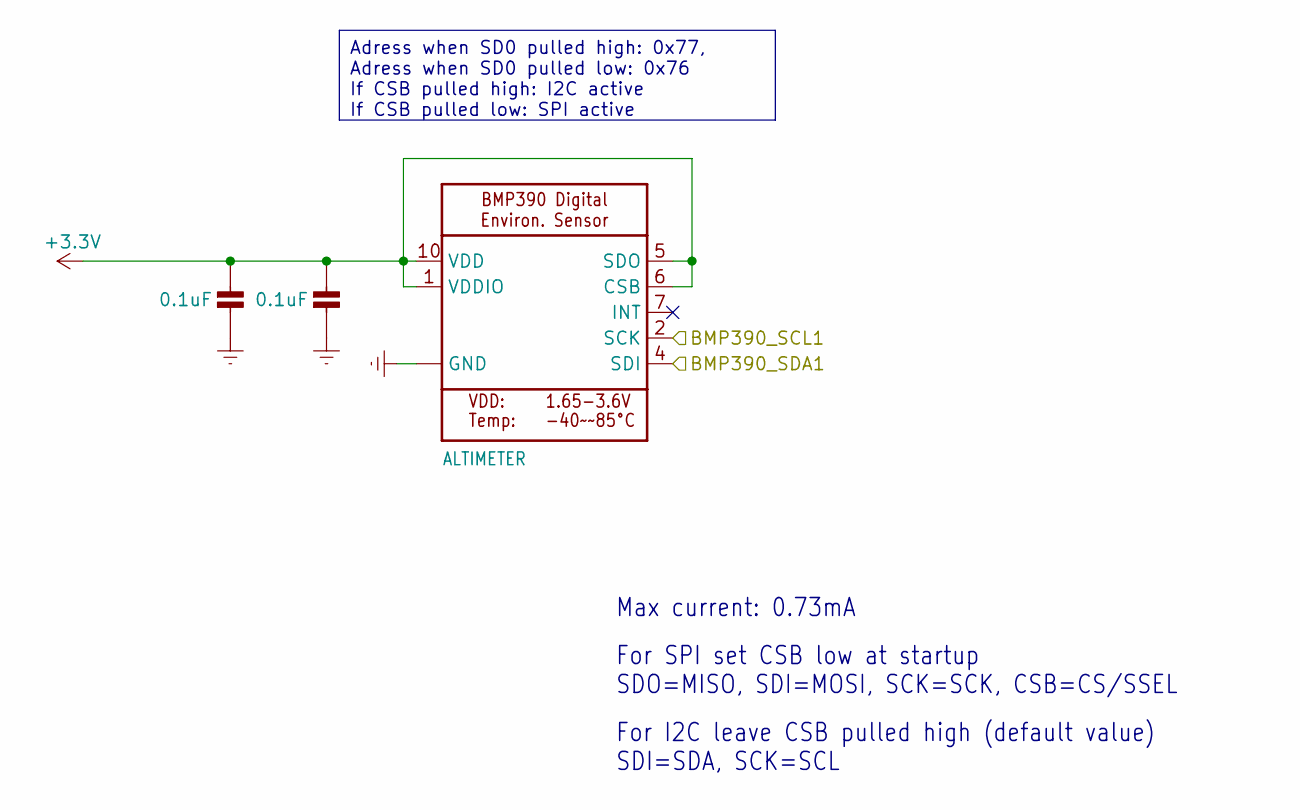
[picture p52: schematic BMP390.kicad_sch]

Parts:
BMP1: ALTIMETER; BMP388; Mouser Part Number 262-BMP390; LCSC C2684802
C34, C35: 0.1uF; R_0603_1608Metric_Pad0.98x0.95mm_HandSolder; LCSC C1590

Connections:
+3.3V: BMP1.1 (VDDIO), BMP1.5 (SDO), BMP1.6 (CSB), BMP1.10 (VDD), C34.1, C35.1; also elsewhere on the board
/BMP390_SCL1: BMP1.2 (SCK); also elsewhere on the board
/BMP390_SDA1: BMP1.4 (SDI); also elsewhere on the board
GNDREF: BMP1.3 (GND), BMP1.8 (GND), BMP1.9 (GND), C34.2, C35.2; also elsewhere on the board

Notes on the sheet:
For SPI set CSB low at startup SDO=MISO, SDI=MOSI, SCK=SCK, CSB=CS/SSEL
Max current: 0.73mA
For I2C leave CSB pulled high (default value) SDI=SDA, SCK=SCL
Adress when SD0 pulled high: 0x77, Adress when SD0 pulled low: 0x76 If CSB pulled high: I2C active If CSB pulled low: SPI active

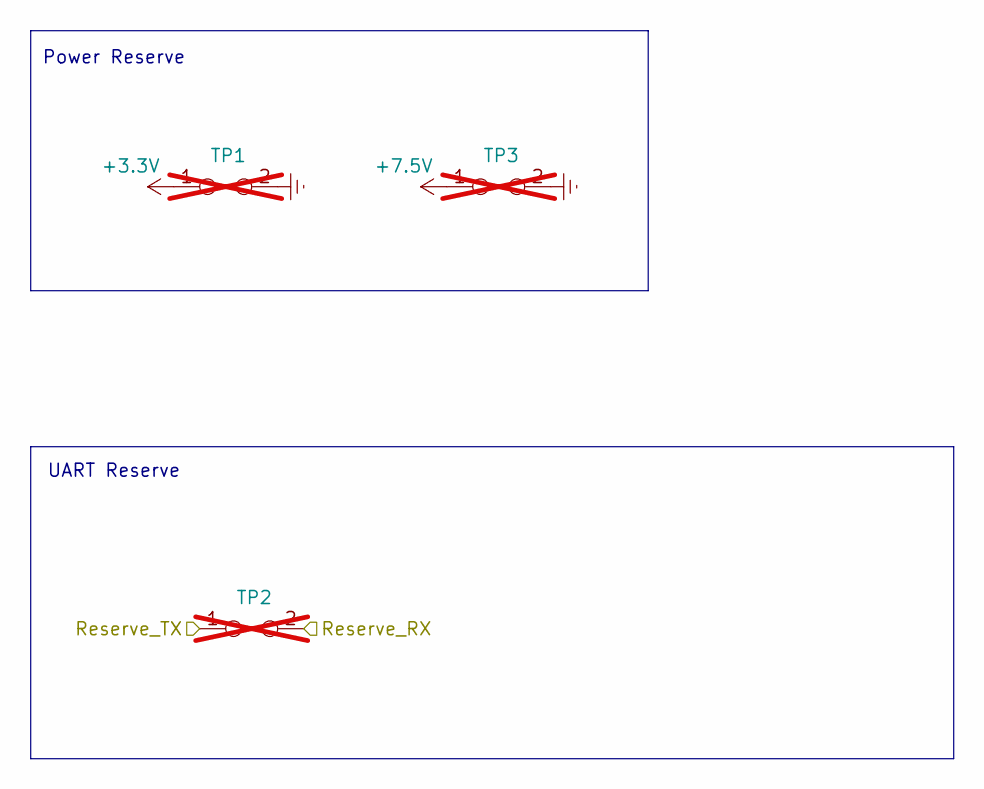
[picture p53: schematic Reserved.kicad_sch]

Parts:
TP1, TP2, TP3: TestPoint_2Pole; TestPoint_2Pads_Pitch2.54mm_Drill0.8mm; not fitted

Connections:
+3.3V: TP1.1; also elsewhere on the board
+7.5V: TP3.1; also elsewhere on the board
/Reserve_RX: TP2.2; also elsewhere on the board
/Reserve_TX: TP2.1; also elsewhere on the board
GNDREF: TP1.2, TP3.2; also elsewhere on the board

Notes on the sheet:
Power Reserve
UART Reserve

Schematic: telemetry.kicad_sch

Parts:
JST-GH-1: TELEMETRY; JST_GH_BM04B-GHS-TBT_1x04-1MP_P1.25mm_Vertical; Mouser Part Number 306-BM04BGHSTBTLFSNN

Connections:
+3.3V: JST-GH-1.1; also elsewhere on the board
/Lora_RX: JST-GH-1.4; also elsewhere on the board
/Lora_TX: JST-GH-1.3; also elsewhere on the board
GNDREF: JST-GH-1.2; also elsewhere on the board

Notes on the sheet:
We will be using two LoRa Module EBYTE E22-T Series

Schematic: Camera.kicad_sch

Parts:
JST-GH-2: CAMERA; JST_GH_BM04B-GHS-TBT_1x04-1MP_P1.25mm_Vertical; Mouser Part Number 306-BM04BGHSTBTLFSNN

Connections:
+7.5V: JST-GH-2.1; also elsewhere on the board
/Cam_RX: JST-GH-2.3; also elsewhere on the board
/Cam_TX: JST-GH-2.4; also elsewhere on the board
GNDREF: JST-GH-2.2; also elsewhere on the board

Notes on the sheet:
from 80ms to 200ma according to voltage, RunCam Split 4-25 has the DVR inside already. Other choices to look at, would need to connect a bypass capacitor before cam in case of noise + inductor
Cameras use JST GH connectors

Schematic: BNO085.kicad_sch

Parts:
BNO1: IMU; BNO085; Mouser Part Number 526-BNO085; LCSC C5189642
C29, C30, C31: 0.1uF; R_0603_1608Metric_Pad0.98x0.95mm_HandSolder; LCSC C1590
C32, C33: 22pF; R_0603_1608Metric_Pad0.98x0.95mm_HandSolder; LCSC C49326308
R14, R15, R16: 4.7k; R_0603_1608Metric_Pad0.98x0.95mm_HandSolder; LCSC C23162
R17: 10k; R_0603_1608Metric_Pad0.98x0.95mm_HandSolder; LCSC C25804
Y3: 32.768kHz; Crystal_SMD_2012-2Pin_2.0x1.2mm_HandSoldering; Mouser Part Number 815-ABS06-32.7K-1-T; LCSC C1985397

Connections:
+3.3V: BNO1.3 (VDD), BNO1.28 (VDDIO), C29.1, C30.1, R14.1, R15.2, R17.1; also elsewhere on the board
/BNO085_RST: BNO1.11 (NRST); also elsewhere on the board
/BNO085_SCL: BNO1.19 (H_SCL/SCLK/RX), R14.2; also elsewhere on the board
/BNO085_SDA: BNO1.20 (H_SDA/MISO/TX), R15.1; also elsewhere on the board
/IMU BNO085/CAP: BNO1.9 (CAP), C31.2
GNDREF: BNO1.2 (GND), BNO1.5 (PS1), BNO1.6 (PS0/WAKE), BNO1.10 (CLKSEL0), BNO1.25 (GNDIO), C29.2, C30.2, C31.1, C32.2, C33.2, R16.2; also elsewhere on the board
unnamed: BNO1.4 (BOOTN), R17.2
unnamed: BNO1.26 (CLKSEL1/XOUT32), C33.1, Y3.1
unnamed: BNO1.17 (H_SA0/MOSI), R16.1
unnamed: BNO1.27 (XIN32), C32.1, Y3.2

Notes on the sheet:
Max Current: 30 mA
SA0 is default low, so I2C ADDR = 1001010 (0x4A)
CEVA recommends using a crystal with tolerance50ppm with 12.5pF capacitor loading.
Slave I2C keep unconnected

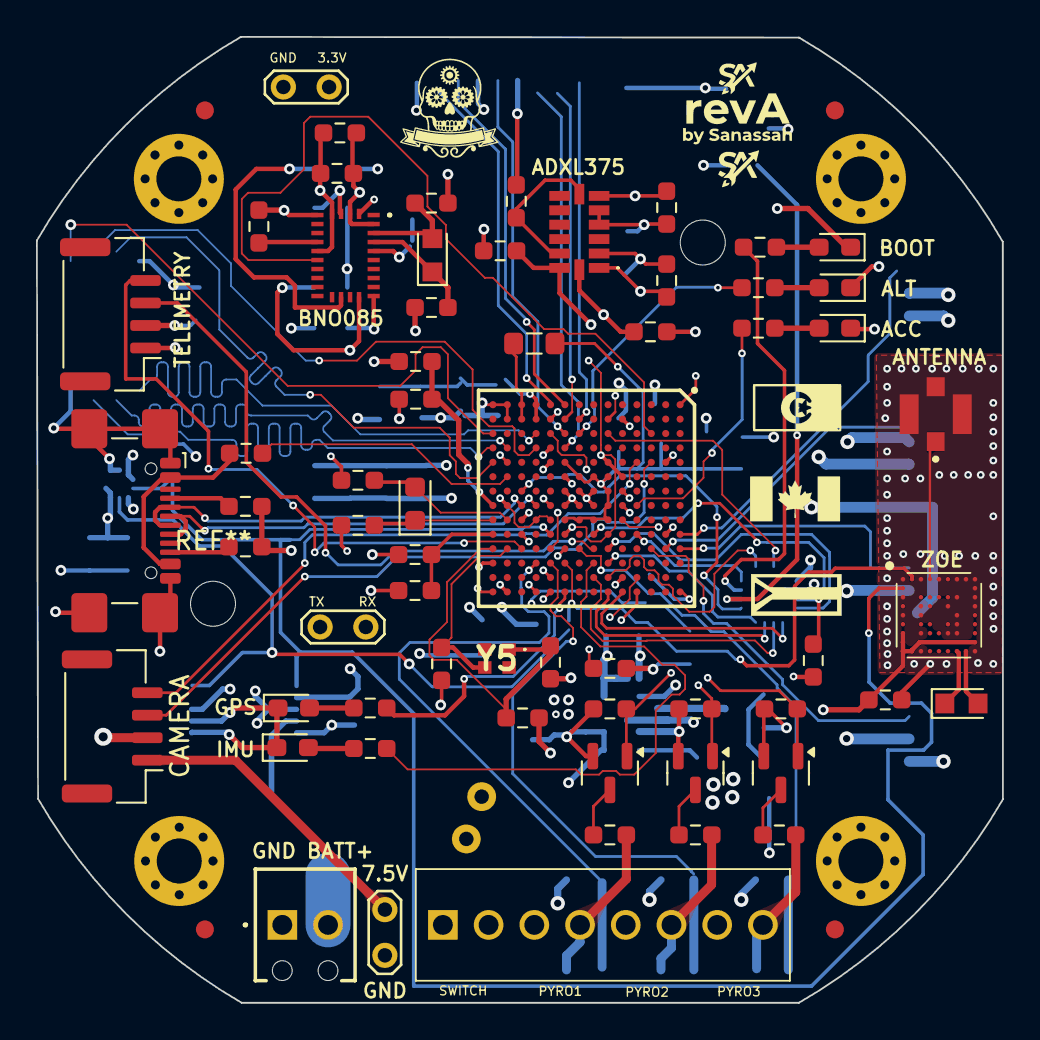
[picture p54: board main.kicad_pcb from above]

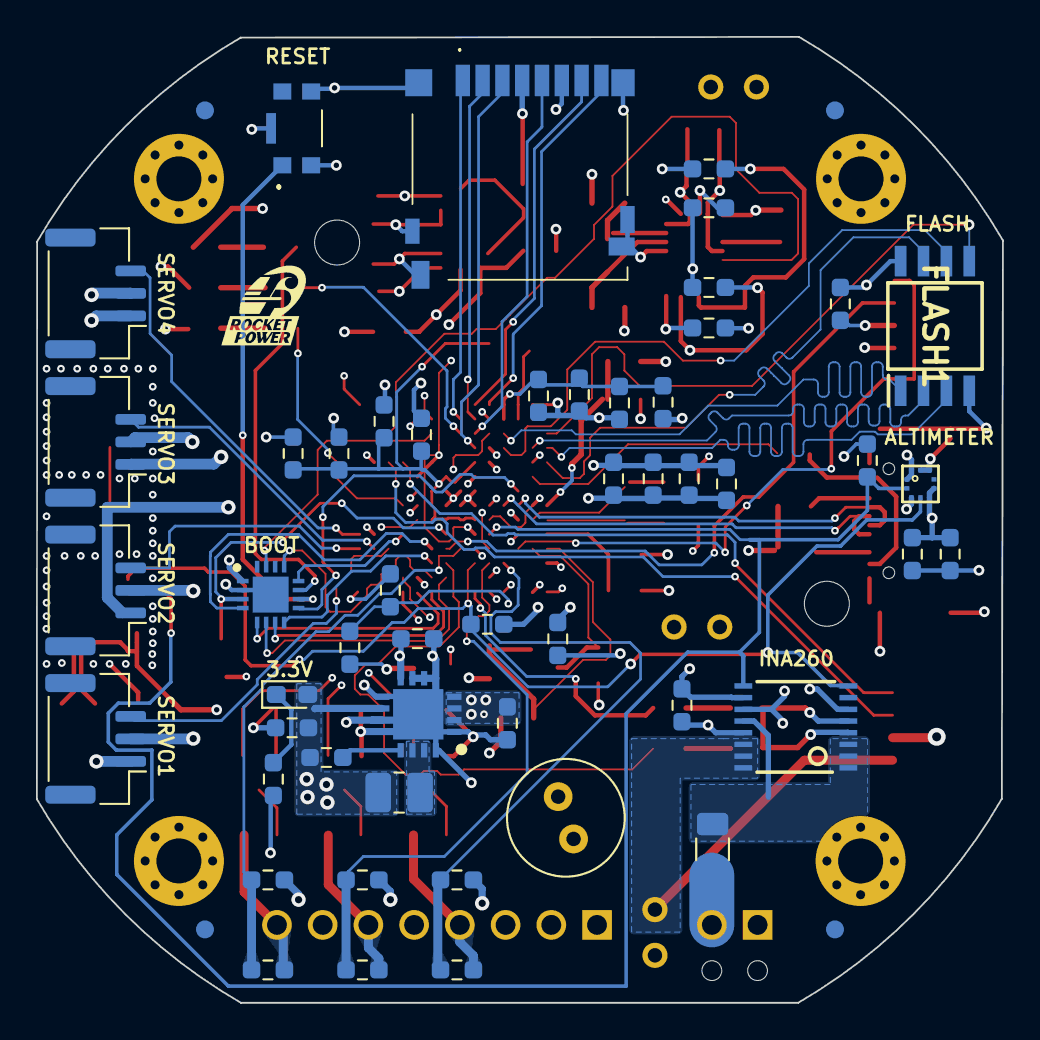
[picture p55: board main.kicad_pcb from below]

Board: 4 copper layers, 53.7 x 53.7 mm, 121 parts (55 on the bottom side), 97 nets.

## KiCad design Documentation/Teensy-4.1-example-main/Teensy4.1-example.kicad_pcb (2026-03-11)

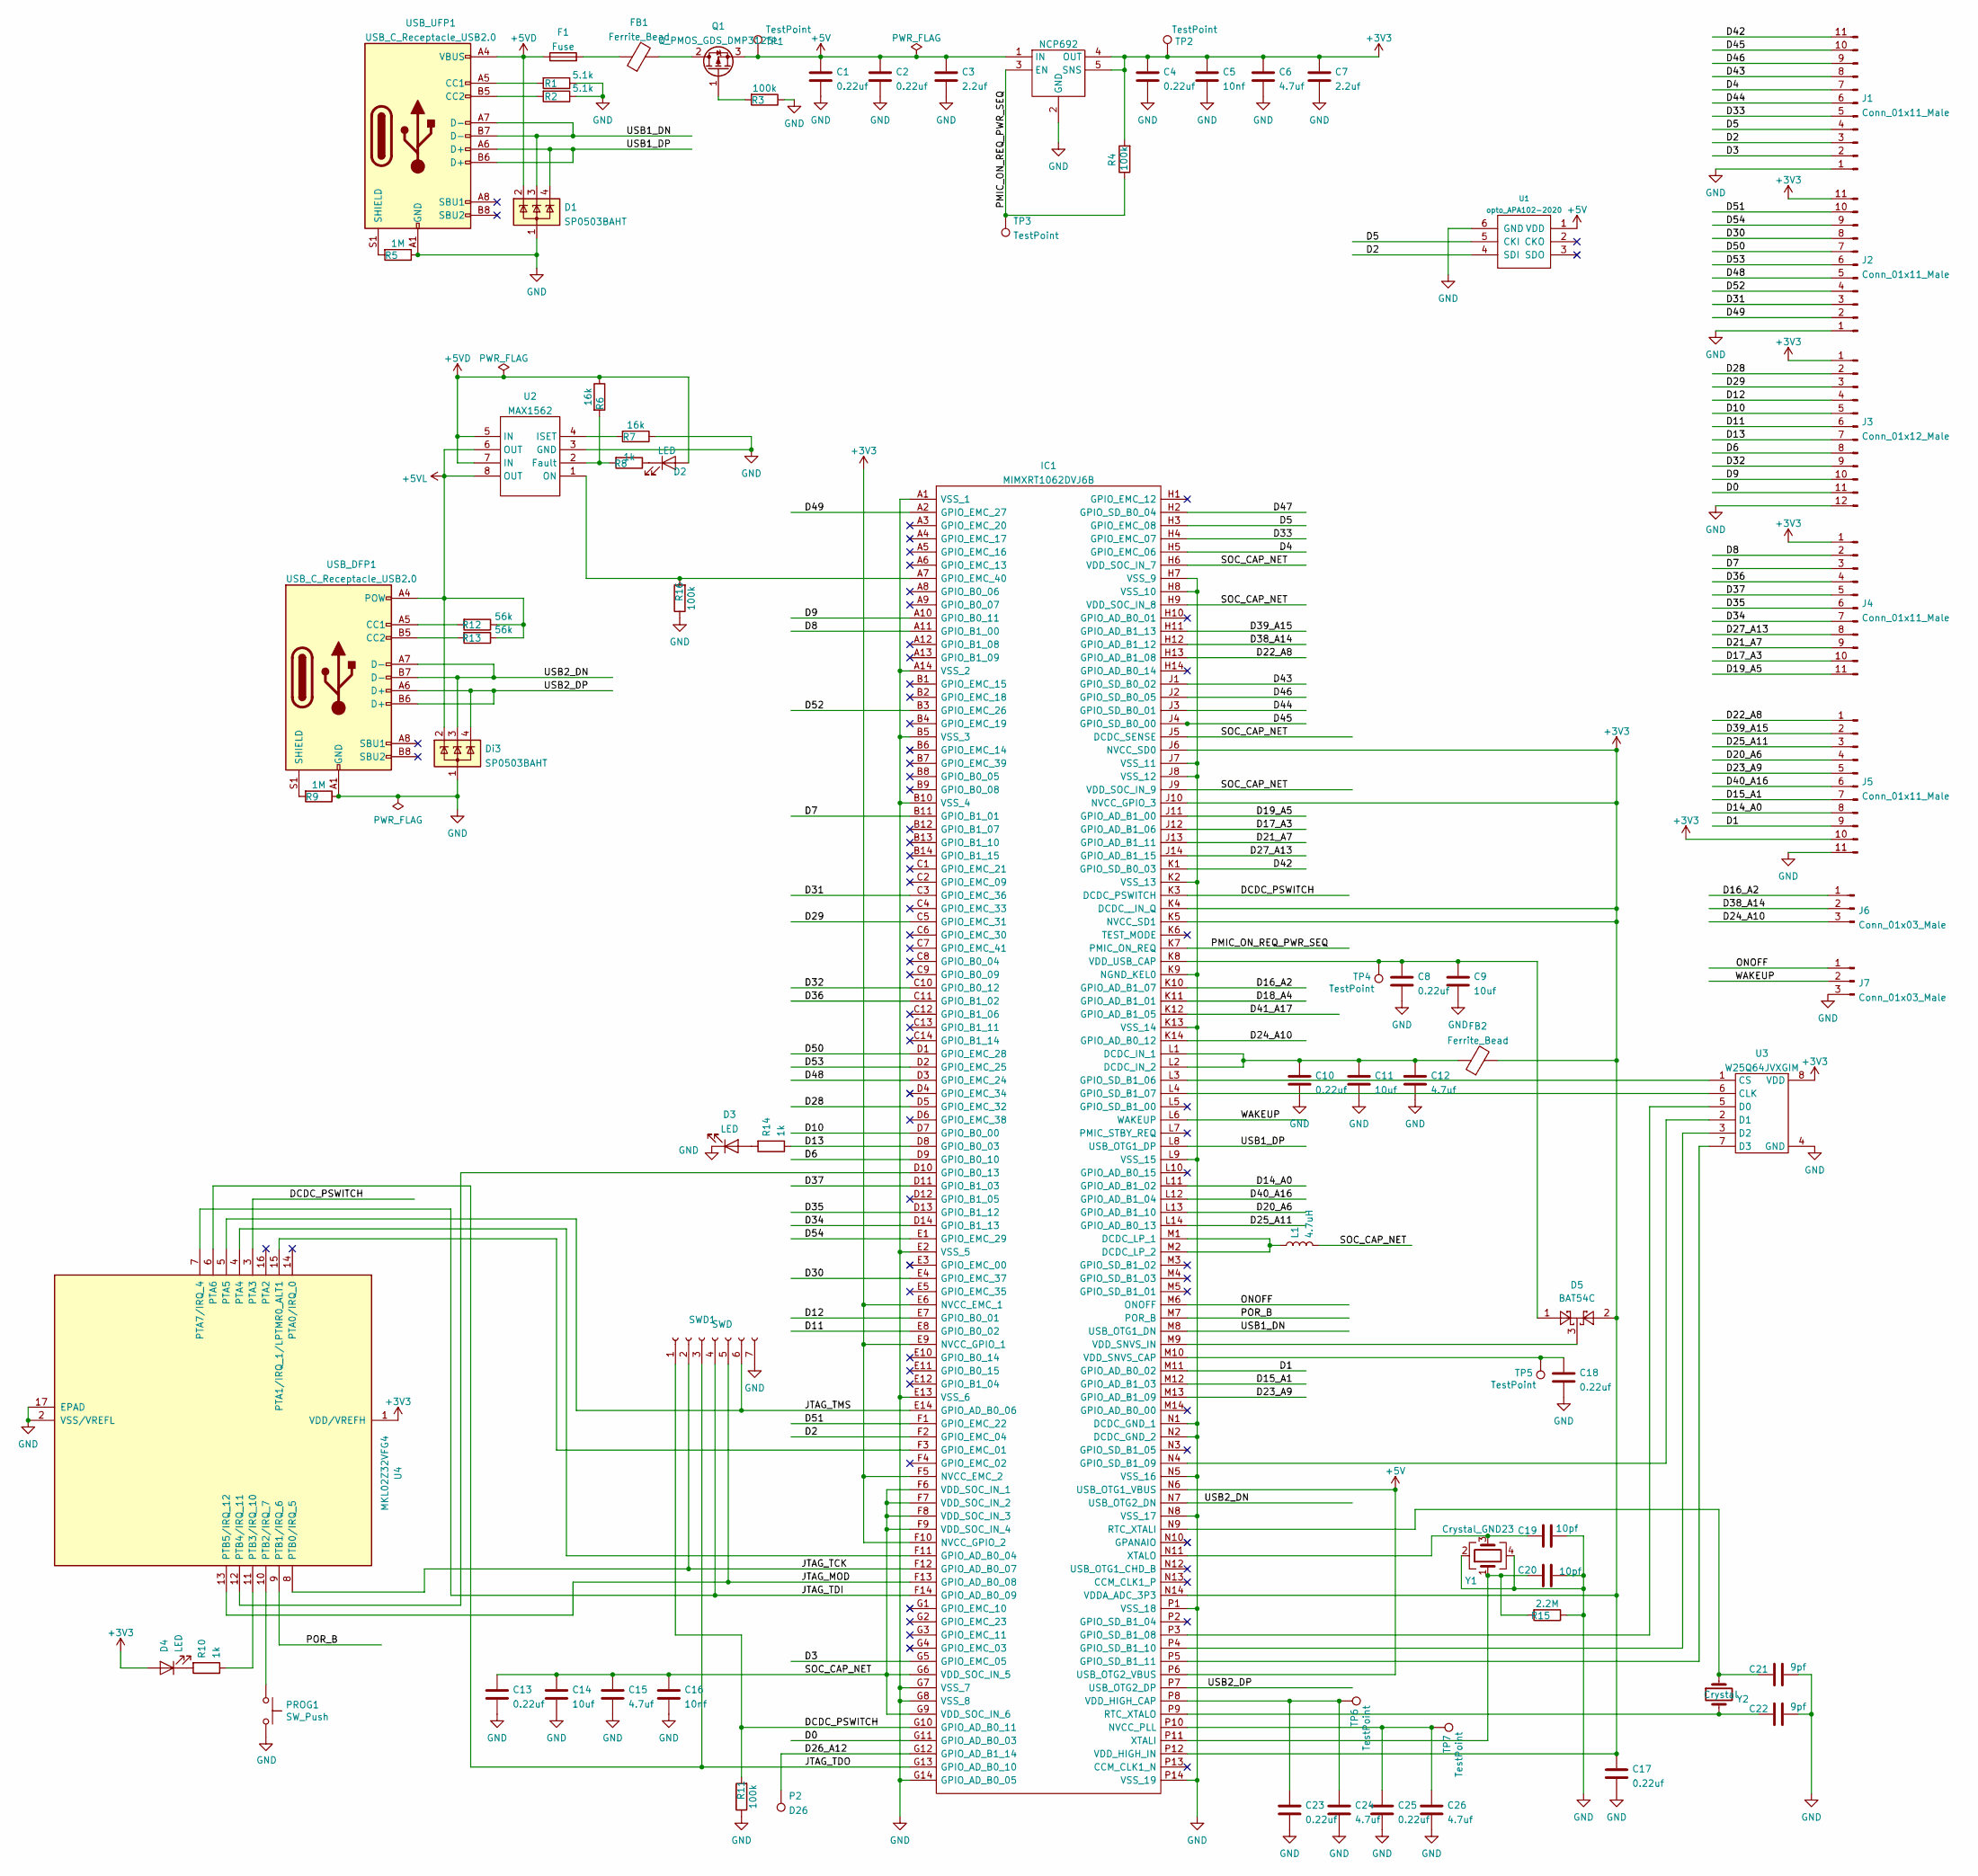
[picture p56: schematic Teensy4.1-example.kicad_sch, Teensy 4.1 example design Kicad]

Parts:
C1, C2, C4, C8, C10, C13, C17, C18, C23, C25: 0.22uf; C_0603_1608Metric; MPN CC0603KRX7R6BB224
C3, C7: 2.2uf; C_0603_1608Metric; MPN CL10B225KP8NNNC
C5, C16: 10nf; C_0603_1608Metric; MPN 0603B103K160CT
C6, C12, C15, C24, C26: 4.7uf; C_0603_1608Metric; MPN CL10B475KQ8NQNC
C9, C11, C14: 10uf; C_0805_2012Metric; MPN GRM21BR71A106KA73K
C19, C20: 10pf; C_0603_1608Metric; MPN CC0603KRNPO9BN100
C21, C22: 9pf; C_0603_1608Metric; MPN GRM1885C1H9R0DA01D
D1: SP0503BAHT; SOT-143
D2, D3, D4: LED; LED_0402_1005Metric
D5: BAT54C; SOT-23
Di3: SP0503BAHT; SOT-143
F1: Fuse; R_0805_2012Metric; MPN 0ZCK0050FF2E
FB1, FB2: Ferrite_Bead; R_0805_2012Metric; MPN FBMH2012HM121-T‎
IC1: MIMXRT1062DVJ6B; BGA196C80P14X14_1200X1200X152; Mouser Part Number 771-MIMXRT1062DVJ6B
J1, J2, J4, J5: Conn_01x11_Male; PinHeader_1x11_P2.54mm_Vertical
J3: Conn_01x12_Male; PinHeader_1x12_P2.54mm_Vertical
J6, J7: Conn_01x03_Male; PinHeader_1x03_P2.54mm_Vertical
L1: 4.7uH; C_0805_2012Metric; MPN LQM21PN4R7MGRD
NCP692: OnSemi NCP692, fixed version; DFN-6-1EP_3x3mm_P0.95mm_EP1.7x2.6mm; MPN NCP692MN33T2G
P2: D26; PinHeader_1x01_P1.00mm_Vertical
PROG1: SW_Push; KMR241GLFS; MPN KMR241GLFS
Q1: Q_PMOS_GDS_DMP3125L; SOT-23
R1, R2: 5.1k; R_0603_1608Metric; MPN RC0603FR-075K1L
R3, R4, R11, R16: 100k; R_0603_1608Metric
R5, R9: 1M; R_0603_1608Metric
R6, R7: 16k; R_0603_1608Metric
R8, R10, R14: 1k; R_0402_1005Metric
R12, R13: 56k; R_0603_1608Metric; MPN RMCF0603FT56K0
R15: 2.2M; R_0603_1608Metric
SWD1: SWD; PinHeader_1x07_P1.27mm_Vertical
TP1, TP2, TP3, TP4, TP5, TP6, TP7: TestPoint; TestPoint_Pad_D1.0mm
U1: opto_APA102-2020; APA102-2020
U2: MAX1562; SO-8_3.9x4.9mm_P1.27mm
U3: W25Q64JVXGIM; XSON8_4x4mm
U4: MKL02Z32VFG4; QFN-16-1EP_3x3mm_P0.5mm_EP1.8x1.8mm; MPN Custom firmware part
USB_DFP1: USB_C_Receptacle_USB2.0; TYPE-C-31-M-14
USB_UFP1: USB_C_Receptacle_USB2.0; TYPE-C-31-M-14
Y1: Crystal_GND23; Crystal_SMD_Abracon_ABM3B-4Pin_5.0x3.2mm
Y2: Crystal; Crystal_SMD_2012-2Pin_2.0x1.2mm; MPN ABS06-32.768KHZ-9-1-T

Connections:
+3V3: C4.1, C5.1, C6.1, C7.1, C17.1, D4.2 (A), D5.2, FB2.2, IC1.E6 (NVCC_EMC_1), IC1.E9 (NVCC_GPIO_1), IC1.F5 (NVCC_EMC_2), IC1.F10 (NVCC_GPIO_2), IC1.J6 (NVCC_SD0), IC1.J10 (NVCC_GPIO_3), IC1.K4 (DCDC__IN_Q), IC1.K5 (NVCC_SD1), IC1.N14 (VDDA_ADC_3P3), IC1.P12 (VDD_HIGH_IN), J2.11, J3.1, J4.1, J5.10, NCP692.4 (OUT), NCP692.5 (SNS), R4.2, TP2.1, U3.8 (VDD), U4.1 (VDD/VREFH)
+5V: C1.1, C2.1, C3.1, IC1.N6 (USB_OTG1_VBUS), IC1.P6 (USB_OTG2_VBUS), NCP692.1 (IN), NCP692.6 (IN), Q1.3 (S), TP1.1, U1.1 (VDD)
+5VD: D1.2 (K), D2.2 (A), F1.1, R6.1, U2.5 (IN), U2.7 (IN), USB_UFP1.A4 (VBUS), USB_UFP1.A9 (VBUS), USB_UFP1.B4 (VBUS), USB_UFP1.B9 (VBUS)
+5VL: Di3.2 (K), R12.1, R13.1, U2.6 (OUT), U2.8 (OUT), USB_DFP1.A4 (POW), USB_DFP1.A9 (POW), USB_DFP1.B4 (POW), USB_DFP1.B9 (POW)
/D0: IC1.G11 (GPIO_AD_B0_03), J3.11
/D1: IC1.M11 (GPIO_AD_B0_02), J5.9
/D2: IC1.F2 (GPIO_EMC_04), J1.3, U1.4 (SDI)
/D3: IC1.G5 (GPIO_EMC_05), J1.2
/D4: IC1.H5 (GPIO_EMC_06), J1.7
/D5: IC1.H3 (GPIO_EMC_08), J1.4, U1.5 (CKI)
/D6: IC1.D9 (GPIO_B0_10), J3.8
/D7: IC1.B11 (GPIO_B1_01), J4.3
/D8: IC1.A11 (GPIO_B1_00), J4.2
/D9: IC1.A10 (GPIO_B0_11), J3.10
/D10: IC1.D7 (GPIO_B0_00), J3.5
/D11: IC1.E8 (GPIO_B0_02), J3.6
/D12: IC1.E7 (GPIO_B0_01), J3.4
/D13: IC1.D8 (GPIO_B0_03), J3.7, R14.1
/D14_A0: IC1.L11 (GPIO_AD_B1_02), J5.8
/D15_A1: IC1.M12 (GPIO_AD_B1_03), J5.7
/D16_A2: IC1.K10 (GPIO_AD_B1_07), J6.1
/D17_A3: IC1.J12 (GPIO_AD_B1_06), J4.10
/D18_A4: IC1.K11 (GPIO_AD_B1_01)
/D19_A5: IC1.J11 (GPIO_AD_B1_00), J4.11
/D20_A6: IC1.L13 (GPIO_AD_B1_10), J5.4
/D21_A7: IC1.J13 (GPIO_AD_B1_11), J4.9
/D22_A8: IC1.H13 (GPIO_AD_B1_08), J5.1
/D23_A9: IC1.M13 (GPIO_AD_B1_09), J5.5
/D24_A10: IC1.K14 (GPIO_AD_B0_12), J6.3
/D25_A11: IC1.L14 (GPIO_AD_B0_13), J5.3
/D26_A12: IC1.G12 (GPIO_AD_B1_14), P2.1
/D27_A13: IC1.J14 (GPIO_AD_B1_15), J4.8
/D28: IC1.D5 (GPIO_EMC_32), J3.2
/D29: IC1.C5 (GPIO_EMC_31), J3.3
/D30: IC1.E4 (GPIO_EMC_37), J2.8
/D31: IC1.C3 (GPIO_EMC_36), J2.3
/D32: IC1.C10 (GPIO_B0_12), J3.9
/D33: IC1.H4 (GPIO_EMC_07), J1.5
/D34: IC1.D14 (GPIO_B1_13), J4.7
/D35: IC1.D13 (GPIO_B1_12), J4.6
/D36: IC1.C11 (GPIO_B1_02), J4.4
/D37: IC1.D11 (GPIO_B1_03), J4.5
/D38_A14: IC1.H12 (GPIO_AD_B1_12), J6.2
/D39_A15: IC1.H11 (GPIO_AD_B1_13), J5.2
/D40_A16: IC1.L12 (GPIO_AD_B1_04), J5.6
/D41_A17: IC1.K12 (GPIO_AD_B1_05)
/D42: IC1.K1 (GPIO_SD_B0_03), J1.11
/D43: IC1.J1 (GPIO_SD_B0_02), J1.8
/D44: IC1.J3 (GPIO_SD_B0_01), J1.6
/D45: IC1.J4 (GPIO_SD_B0_00), J1.10
/D46: IC1.J2 (GPIO_SD_B0_05), J1.9
/D47: IC1.H2 (GPIO_SD_B0_04)
/D48: IC1.D3 (GPIO_EMC_24), J2.5
/D49: IC1.A2 (GPIO_EMC_27), J2.2
/D50: IC1.D1 (GPIO_EMC_28), J2.7
/D51: IC1.F1 (GPIO_EMC_22), J2.10
/D52: IC1.B3 (GPIO_EMC_26), J2.4
/D53: IC1.D2 (GPIO_EMC_25), J2.6
/D54: IC1.E1 (GPIO_EMC_29), J2.9
/DCDC_PSWITCH: IC1.G10 (GPIO_AD_B0_11), IC1.K3 (DCDC_PSWITCH), R11.2, SWD1.1, U4.3 (PTA3)
/JTAG_MOD: IC1.F13 (GPIO_AD_B0_08), SWD1.5, U4.13 (PTB5/IRQ_12)
/JTAG_TCK: IC1.F12 (GPIO_AD_B0_07), SWD1.2, U4.8 (PTB0/IRQ_5)
/JTAG_TDI: IC1.F14 (GPIO_AD_B0_09), SWD1.4, U4.7 (PTA7/IRQ_4)
/JTAG_TDO: IC1.G13 (GPIO_AD_B0_10), SWD1.3, U4.6 (PTA6)
/JTAG_TMS: IC1.E14 (GPIO_AD_B0_06), SWD1.6, U4.5 (PTA5)
/ONOFF: IC1.M6 (ONOFF), J7.1
/PMIC_ON_REQ_PWR_SEQ: IC1.K7 (PMIC_ON_REQ), NCP692.3 (EN), R4.1, TP3.1
/POR_B: IC1.M7 (POR_B), U4.9 (PTB1/IRQ_6)
/SOC_CAP_NET: C13.1, C14.1, C15.1, C16.1, IC1.F6 (VDD_SOC_IN_1), IC1.F7 (VDD_SOC_IN_2), IC1.F8 (VDD_SOC_IN_3), IC1.F9 (VDD_SOC_IN_4), IC1.G6 (VDD_SOC_IN_5), IC1.G9 (VDD_SOC_IN_6), IC1.H6 (VDD_SOC_IN_7), IC1.H9 (VDD_SOC_IN_8), IC1.J5 (DCDC_SENSE), IC1.J9 (VDD_SOC_IN_9), L1.2
/USB1_DN: D1.3 (K), IC1.M8 (USB_OTG1_DN), USB_UFP1.A7 (D-), USB_UFP1.B7 (D-)
/USB1_DP: D1.4 (K), IC1.L8 (USB_OTG1_DP), USB_UFP1.A6 (D+), USB_UFP1.B6 (D+)
/USB2_DN: Di3.3 (K), IC1.N7 (USB_OTG2_DN), USB_DFP1.A7 (D-), USB_DFP1.B7 (D-)
/USB2_DP: Di3.4 (K), IC1.P7 (USB_OTG2_DP), USB_DFP1.A6 (D+), USB_DFP1.B6 (D+)
/WAKEUP: IC1.L6 (WAKEUP), J7.2
GND: C1.2, C2.2, C3.2, C4.2, C5.2, C6.2, C7.2, C8.2, C9.2, C10.2, C11.2, C12.2, C13.2, C14.2, C15.2, C16.2, C17.2, C18.2, C19.2, C20.2, C21.2, C22.2, C23.2, C24.2, C25.2, C26.2, D1.1 (A), D3.1 (K), Di3.1 (A), IC1.A1 (VSS_1), IC1.A14 (VSS_2), IC1.B5 (VSS_3), IC1.B10 (VSS_4), IC1.E2 (VSS_5), IC1.E13 (VSS_6), IC1.G7 (VSS_7), IC1.G8 (VSS_8), IC1.G14 (GPIO_AD_B0_05), IC1.H7 (VSS_9), IC1.H8 (VSS_10), IC1.J7 (VSS_11), IC1.J8 (VSS_12), IC1.K2 (VSS_13), IC1.K9 (NGND_KEL0), IC1.K13 (VSS_14), IC1.L9 (VSS_15), IC1.N1 (DCDC_GND_1), IC1.N2 (DCDC_GND_2), IC1.N5 (VSS_16), IC1.N8 (VSS_17), IC1.P1 (VSS_18), IC1.P14 (VSS_19), J1.1, J2.1, J3.12, J5.11, J7.3, NCP692.2 (GND), NCP692.7 (GND), PROG1.2, R1.1, R2.1, R3.1, R5.1, R7.1, R9.1, R11.1, R15.1, R16.1, SWD1.7, U1.6 (GND), U2.3 (GND), U3.4 (GND), U4.2 (VSS/VREFL), U4.17 (EPAD), USB_DFP1.A1 (GND), USB_DFP1.A12 (GND), USB_DFP1.B1 (GND), USB_DFP1.B12 (GND), USB_UFP1.A1 (GND), USB_UFP1.A12 (GND), USB_UFP1.B1 (GND), USB_UFP1.B12 (GND), Y1.2, Y1.4
unnamed: C8.1, C9.1, D5.1, IC1.K8 (VDD_USB_CAP), TP4.1
unnamed: C10.1, C11.1, C12.1, FB2.1, IC1.L1 (DCDC_IN_1), IC1.L2 (DCDC_IN_2)
unnamed: C18.1, IC1.M10 (VDD_SNVS_CAP), TP5.1
unnamed: C19.1, IC1.N11 (XTALO), Y1.3
unnamed: C20.1, IC1.P11 (XTALI), R15.2, Y1.1
unnamed: C23.1, C24.1, IC1.P8 (VDD_HIGH_CAP), TP6.1
unnamed: C25.1, C26.1, IC1.P10 (NVCC_PLL), TP7.1
unnamed: D2.1 (K), R8.1
unnamed: D3.2 (A), R14.2
unnamed: D4.1 (K), R10.2
unnamed: D5.3, IC1.M9 (VDD_SNVS_IN)
unnamed: F1.2, FB1.1
unnamed: FB1.2, Q1.2 (D)
unnamed: IC1.A7 (GPIO_EMC_40), R16.2, U2.1 (ON)
unnamed: IC1.D10 (GPIO_B0_13), U4.12 (PTB4/IRQ_11)
unnamed: IC1.F3 (GPIO_EMC_01), U4.15 (PTA1/IRQ_1/LPTMR0_ALT1)
unnamed: IC1.F11 (GPIO_AD_B0_04), U4.4 (PTA4)
unnamed: IC1.L3 (GPIO_SD_B1_06), U3.1 (CS)
unnamed: IC1.L4 (GPIO_SD_B1_07), U3.6 (CLK)
unnamed: IC1.M1 (DCDC_LP_1), IC1.M2 (DCDC_LP_2), L1.1
unnamed: IC1.N4 (GPIO_SD_B1_09), U3.2 (D1)
unnamed: IC1.P3 (GPIO_SD_B1_08), U3.5 (D0)
unnamed: IC1.P4 (GPIO_SD_B1_10), U3.3 (D2)
unnamed: IC1.P5 (GPIO_SD_B1_11), U3.7 (D3)
unnamed: PROG1.1, U4.10 (PTB2/IRQ_7)
unnamed: Q1.1 (G), R3.2
unnamed: R1.2, USB_UFP1.A5 (CC1)
unnamed: R2.2, USB_UFP1.B5 (CC2)
unnamed: R5.2, USB_UFP1.S1 (SHIELD)
unnamed: R6.2, R8.2, U2.2 (Fault)
unnamed: R7.2, U2.4 (ISET)
unnamed: R9.2, USB_DFP1.S1 (SHIELD)
unnamed: R10.1, U4.11 (PTB3/IRQ_10)
unnamed: R12.2, USB_DFP1.A5 (CC1)
unnamed: R13.2, USB_DFP1.B5 (CC2)

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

Board: 4 copper layers, 61.5 x 47.5 mm, 80 parts (0 on the bottom side), 109 nets.

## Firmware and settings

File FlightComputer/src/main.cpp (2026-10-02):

#include <Arduino.h>
#include <Wire.h>
#include <SD.h>
#include <elapsedMillis.h>

#include "config.h"
#include "DebugPrint.h"
#include "sensors/SensorManager.h"
#include "states/StateMachine.h"
#include "telemetry/LoRa.h"
#include "telemetry/TelemetryManager.h"
#include "storage/DataLogger.h"
#include "control/PyroController.h"
#include "control/CameraController.h"
#include "control/FinController.h"
#include "control/AttitudeController.h"
#include "control/StatusLED.h"
#include "safety/BackupDeploy.h"

// ===== Global objects =====
SensorManager      sensors;
PyroController     pyro;
StateMachine       fsm(pyro);
LoRaRadio          radio;
FinController      fins;
AttitudeController attitude;
CameraController   camera;
DataLogger         logger;
TelemetryManager   telem(radio, fsm, pyro, fins, camera, logger, attitude);
StatusLED          statusLed;
// Independent of fsm/pyro's armed state on purpose -- see BackupDeploy.h.
BackupDeploy        backupDeploy;

// ===== Timing =====
elapsedMillis loopTimer;     // tracks time since last loop start
uint32_t      loopCount    = 0;
uint32_t      loopMaxUs    = 0;
FlightState   prevState    = FlightState::IDLE;
// Previous loop's real measured duration -- fed into telem.update() for
// HITLResponsePacket.loop_us (see TelemetryManager.h). One loop lagged
// since this loop's own elapsed time isn't known until section 6, after
// telem.update() has already run.
uint32_t      lastLoopElapsedUs = 0;

// TEMPORARY diagnostic -- per-stage breakdown of loopMaxUs above, so a
// bench run pinpoints WHICH stage is stalling instead of just confirming
// that something is. See SensorManager::update()'s own breakdown for a
// further split of the sensors stage specifically (I2C reads across 5
// sensors on 3 Wire buses, one of which -- Wire1 -- is shared by baro/gps/
// power). Remove once the actual stall source is found and fixed.
uint32_t maxSensorsUs = 0, maxControlUs = 0, maxLogUs = 0, maxTelemUs = 0;

// ===== Helpers =====
static void printSensorReport(bool sdOk) {
    const FlightData& d = sensors.data();
    DEBUG_SERIAL.println("--- Sensor init report ---");
    DEBUG_SERIAL.print("  IMU   (BNO085 Wire  0x4A): "); DEBUG_SERIAL.println(d.imu_ok   ? "OK" : "FAIL");
    DEBUG_SERIAL.print("  Baro  (BMP390 Wire1 0x77): "); DEBUG_SERIAL.println(d.baro_ok  ? "OK" : "FAIL");
    DEBUG_SERIAL.print("  Accel (ADXL375 Wire2 0x1D): "); DEBUG_SERIAL.println(d.accel_ok ? "OK" : "FAIL");
    DEBUG_SERIAL.print("  GPS   (ZOEM8  Wire1 0x42): "); DEBUG_SERIAL.println(d.gps_ok   ? "OK" : "FAIL");
    DEBUG_SERIAL.print("  Power (INA260 Wire1 0x40): "); DEBUG_SERIAL.println(d.power_ok  ? "OK" : "FAIL");
    DEBUG_SERIAL.print("  SD    (BUILTIN_SDCARD):    "); DEBUG_SERIAL.println(sdOk ? "OK" : "FAIL");
    DEBUG_SERIAL.println("--------------------------");
}

// =================================================================
void setup() {
    Serial.begin(115200);
    while (!Serial && millis() < 5000);

    DEBUG_SERIAL.println("\n=================================");
    DEBUG_SERIAL.println(" RocketFlightComputer v0.1");
    DEBUG_SERIAL.println(" Custom MIMXRT1062 / Teensy 4.1");
    DEBUG_SERIAL.println("=================================\n");

    // ---- Status LEDs ----
    statusLed.begin();

    // ---- Sensors ----
    DEBUG_SERIAL.println("[INIT] Sensors...");
    bool sensorsOk = sensors.begin();

    // ---- SD card ---- (before the report below, so it reflects the real attempt --
    // logger.open() is self-contained and probes the card itself)
    DEBUG_SERIAL.println("[INIT] SD card...");
    if (!logger.open()) {
        DEBUG_SERIAL.println("[INIT] WARNING: SD card failed. Logging disabled.");
    }

    printSensorReport(logger.cardPresent());
    statusLed.update(sensors.data());
    if (!sensorsOk) {
        DEBUG_SERIAL.println("[INIT] CRITICAL: IMU or barometer failed. Halting.");
        while (true) { statusLed.update(sensors.data()); delay(50); }
    }

    // ---- Calibrate barometer at launch site ----
    DEBUG_SERIAL.println("[INIT] Calibrating barometer (2s)...");
    sensors.calibrateBaro();
    DEBUG_SERIAL.println("[INIT] Baro calibrated.");

    // ---- Pyro ----
    DEBUG_SERIAL.println("[INIT] Pyro channels...");
    pyro.begin();
    for (int ch = 1; ch <= PYRO_NUM_CHANNELS; ch++) {
        DEBUG_SERIAL.print("  CH"); DEBUG_SERIAL.print(ch);
        DEBUG_SERIAL.print(" continuity: ");
        DEBUG_SERIAL.println(pyro.continuityOk(ch) ? "OK" : "OPEN (no ematch?)");
    }

    // ---- LoRa / Telemetry ----
    DEBUG_SERIAL.println("[INIT] LoRa radio...");
    if (!telem.begin()) {
        DEBUG_SERIAL.println("[INIT] WARNING: LoRa init failed.");
    }

    // ---- Camera ----
    camera.begin();

    // ---- Fin servos ----
    DEBUG_SERIAL.println("[INIT] Fin servos...");
    fins.begin();

    DEBUG_SERIAL.println("\n[INIT] Boot complete. State: IDLE\n");
    loopTimer = 0;
}

// =================================================================
void loop() {
    uint32_t loopStart = micros();

    // ---- 1. Read all sensors ----
    sensors.update();
    sensors.setState(fsm.state());   // stamp this loop's state onto the snapshot for logging/telemetry
    const FlightData& d = sensors.data();
    statusLed.update(d);
    pyro.update();   // non-blocking fire-pin timeout -- see PyroController.h
    uint32_t tSensors = micros();   // TEMPORARY diagnostic, see maxSensorsUs above

    // ---- 2. Update state machine ----
    fsm.update(d);
    FlightState newState = fsm.state();

    // ---- 2a. Independent backup apogee monitor ----
    // Deliberately unconditional -- no state or armed-flag check here. See
    // BackupDeploy.h for why: if fsm/pyro's state got reset mid-flight
    // (neither survives a reboot), this is the only thing that can still
    // notice the rocket already went through a real boost and reached
    // apogee, and fire the backup channel anyway.
    backupDeploy.update(d, pyro);

    // ---- 2b. Active attitude control ----
    // Two independent reasons to run this, from two independent ground-
    // commanded runtime flags -- see AttitudeController.h for why they're
    // kept separate:
    //   - Real in-flight control (attitude.controlEnabled()): only
    //     meaningful with real airflow over the fins, so POWERED_ASCENT/
    //     COAST only -- not before liftoff, not once the chute's out.
    //   - Ground demo/bench-validation (attitude.demoEnabled()): IDLE or
    //     ARMED, for hand-rotating the airframe and watching the fin
    //     response -- deliberately doesn't require ARMED (pyro doesn't need
    //     to be hot just to watch the fins move), and never runs once real
    //     liftoff moves the state machine past ARMED either way.
    // A no-op entirely when both are false (the default at every boot).
    bool wantAttitudeControl =
        (attitude.controlEnabled() && (newState == FlightState::POWERED_ASCENT ||
                                        newState == FlightState::COAST)) ||
        (attitude.demoEnabled()    && (newState == FlightState::IDLE ||
                                        newState == FlightState::ARMED));
    if (wantAttitudeControl) {
        attitude.update(d, fins);
    }

    // ---- 2c. Raw gyro + absolute tilt + fin-response debug print, DEMO only ----
    // Exists for exactly one purpose: the bench axis-mapping/allocation-sign
    // calibration procedure in config.h/AttitudeController.h. gyro_x/y/z
    // aren't in TelemetryPacket at all (kept out deliberately -- see its
    // size comment), so there's otherwise no live way to see them.
    //
    // The angle terms are the same exact tilt-from-true-vertical computation
    // AttitudeController::update() now uses for its own roll/pitch angle
    // error (atan2/asin off the absolute quaternion via gravity -- no
    // reference latch, see AttitudeController.cpp) -- computed fresh here
    // too rather than read back from the controller, since this print needs
    // to work even when it isn't the one driving the fins. Labeled by raw
    // sensor axis (X/Y), not N/S/E/W or roll/pitch -- figuring out which raw
    // axis IS which compass direction is exactly what hand-tilting the
    // airframe toward each direction and watching these numbers move is for.
    //
    // Gated on demoEnabled() specifically (not wantAttitudeControl, which is
    // also true during real controlEnabled() flight) so this never fires
    // outside an explicit bench session, and rate-limited so it's readable
    // at a glance while slowly rotating the airframe by hand, not a wall of
    // scrolling text. The binary USB telemetry mirror self-suppresses while
    // demoEnabled() (see TelemetryManager.cpp), so this prints clean in a
    // plain serial monitor without any config.h change needed.
    if (attitude.demoEnabled()) {
        static uint32_t lastGyroPrintMs = 0;
        if (debugPrintReady(lastGyroPrintMs, 200)) {
            constexpr float kRadToDeg = 57.29577951308232f;
            float qw = d.quat_w, qx = d.quat_x, qy = d.quat_y, qz = d.quat_z;
            float sinTiltY = 2.0f * (qw * qy - qz * qx);
            sinTiltY = sinTiltY > 1.0f ? 1.0f : (sinTiltY < -1.0f ? -1.0f : sinTiltY);
            float tiltXdeg = atan2f(2.0f * (qw * qx + qy * qz), 1.0f - 2.0f * (qx * qx + qy * qy)) * kRadToDeg;
            float tiltYdeg = asinf(sinTiltY) * kRadToDeg;
            float spinZdeg = atan2f(2.0f * (qw * qz + qx * qy), 1.0f - 2.0f * (qy * qy + qz * qz)) * kRadToDeg;

            Serial.print("[AXIS CAL] gyro rad/s  x=");
            Serial.print(d.gyro_x, 3);
            Serial.print("  y=");
            Serial.print(d.gyro_y, 3);
            Serial.print("  z=");
            Serial.print(d.gyro_z, 3);
            Serial.print("   |   tilt deg (absolute, from level)  X=");
            Serial.print(tiltXdeg, 1);
            Serial.print(" Y=");
            Serial.print(tiltYdeg, 1);
            Serial.print(" spin=");
            Serial.print(spinZdeg, 1);
            Serial.print("   |   fin deg  S=");
            Serial.print(fins.liveCorrectionDeg(1), 1);
            Serial.print(" E=");
            Serial.print(fins.liveCorrectionDeg(2), 1);
            Serial.print(" N=");
            Serial.print(fins.liveCorrectionDeg(3), 1);
            Serial.print(" W=");
            Serial.println(fins.liveCorrectionDeg(4), 1);
        }
    }

    // ---- 3. Handle state transitions ----
    if (newState != prevState) {
        camera.onStateChange(prevState, newState);
        logger.flush();   // force flush on state change to minimise data loss

        // Arm pyro on ARM, disarm on IDLE or LANDED
        if (newState == FlightState::ARMED) {
            pyro.arm();
            // Re-calibrate baro at the actual launch site, not wherever the FCC booted.
            // The rocket should be stationary on the pad when ARM is sent.
            DEBUG_SERIAL.println("[CALIB] Re-calibrating baro at launch site...");
            sensors.calibrateBaro();
            DEBUG_SERIAL.println("[CALIB] Done.");
        }
        if (newState == FlightState::IDLE || newState == FlightState::LANDED) {
            pyro.disarm();
            attitude.reset();   // force both attitude modes back off, nothing carries between sessions
        }

        // Close log after landing
        if (newState == FlightState::LANDED) logger.close();

        prevState = newState;
    }
    uint32_t tControl = micros();   // TEMPORARY diagnostic, see maxSensorsUs above

    // ---- 4. Log data ----
    logger.update(d);
    uint32_t tLog = micros();   // TEMPORARY diagnostic, see maxSensorsUs above

    // ---- 5. Telemetry (send + receive commands) ----
    telem.update(d, lastLoopElapsedUs);
    uint32_t tTelem = micros();   // TEMPORARY diagnostic, see maxSensorsUs above

    // ---- 5b. Execute calibration if requested by ground station ----
    if (telem.calibrateRequested()) {
        DEBUG_SERIAL.println("[CALIB] Calibrating barometer...");
        sensors.calibrateBaro();
        DEBUG_SERIAL.println("[CALIB] Done.");
    }

    // ---- 5c. Soft reset if requested by ground station ----
    // Fresh-boot-equivalent IDLE without an actual power cycle -- see
    // Packet.h's RESET for why this exists (repeated bench/HITL test
    // flights). Touches every piece of RAM-only flight/detection state this
    // file itself owns references to; TelemetryManager only flags the
    // request since it doesn't hold a BackupDeploy reference. Deliberately
    // a manual, ground-commanded action only (GroundStation's "Reset (back
    // to IDLE)" button) -- NOT auto-triggered at the start of a HITL run,
    // since a HITL test needs to already be armed + stabilization-enabled
    // BEFORE the run starts, and an automatic reset there would silently
    // undo that. The correct bench sequence is: Reset -> Arm -> enable
    // stabilization -> THEN start the Simulink run.
    if (telem.resetRequested()) {
        DEBUG_SERIAL.println("[RESET] Soft reset requested -- clearing all flight/detection state.");
        fsm.reset();
        pyro.disarm();
        attitude.reset();
        // attitude.reset() only clears AttitudeController's OWN state (flags,
        // integrators) -- it never told the servos anything, so FinController's
        // _liveUs[] (and thus liveCorrectionDeg()/HITLResponsePacket.fin_deg)
        // otherwise just keeps reporting whatever the PREVIOUS run last
        // commanded until a fresh attitude.update() overwrites it. Explicit
        // zero here closes that gap instead of waiting on the first real
        // control computation to paper over it.
        for (int ch = 1; ch <= SERVO_NUM_CHANNELS; ch++) fins.setCorrectionDeg(ch, 0.0f);
        backupDeploy.reset();
        if (camera.isRecording()) camera.toggleRecording();
        logger.close();
        if (logger.cardPresent()) logger.open();   // fresh log file for the next run, same as a real reboot would get
        prevState = FlightState::IDLE;             // keep this loop's own change-detection var in sync with fsm's new state
        DEBUG_SERIAL.println("[RESET] Done. State: IDLE");
    }

    // ---- 6. Loop timing diagnostics ----
    uint32_t elapsed = micros() - loopStart;
    if (elapsed > loopMaxUs) loopMaxUs = elapsed;
    loopCount++;
    lastLoopElapsedUs = elapsed;   // for next loop's telem.update() call, see its declaration

    // TEMPORARY diagnostic -- see maxSensorsUs above.
    uint32_t sensorsUs = tSensors - loopStart;
    uint32_t controlUs = tControl - tSensors;
    uint32_t logUs     = tLog     - tControl;
    uint32_t telemUs    = tTelem   - tLog;
    if (sensorsUs > maxSensorsUs) maxSensorsUs = sensorsUs;
    if (controlUs > maxControlUs) maxControlUs = controlUs;
    if (logUs     > maxLogUs)     maxLogUs     = logUs;
    if (telemUs   > maxTelemUs)   maxTelemUs   = telemUs;

    // Print loop stats every 5 seconds
    static uint32_t lastStatMs = 0;
    if (debugPrintReady(lastStatMs, 5000)) {
        float hz = loopCount / 5.0f;
        // Printed in ms (3 decimals = full microsecond precision, just
        // relabeled -- e.g. 6952us prints as 6.952ms) rather than raw us.
        DEBUG_SERIAL.print("[LOOP] "); DEBUG_SERIAL.print(hz, 1); DEBUG_SERIAL.print(" Hz | ");
        DEBUG_SERIAL.print("max="); DEBUG_SERIAL.print(loopMaxUs / 1000.0f, 3); DEBUG_SERIAL.print("ms | ");
        DEBUG_SERIAL.print("state="); DEBUG_SERIAL.println(flightStateName(fsm.state()));
        DEBUG_SERIAL.print("[LOOP BREAKDOWN] sensors="); DEBUG_SERIAL.print(maxSensorsUs / 1000.0f, 3);
        DEBUG_SERIAL.print("ms control="); DEBUG_SERIAL.print(maxControlUs / 1000.0f, 3);
        DEBUG_SERIAL.print("ms log="); DEBUG_SERIAL.print(maxLogUs / 1000.0f, 3);
        DEBUG_SERIAL.print("ms telem="); DEBUG_SERIAL.print(maxTelemUs / 1000.0f, 3);
        DEBUG_SERIAL.println("ms  (each is a max over the same 5s window)");
        loopCount  = 0;
        loopMaxUs  = 0;
        maxSensorsUs = maxControlUs = maxLogUs = maxTelemUs = 0;

        sensors.gps().printDebug();
    }

    // Enforce 100 Hz minimum: if this loop ran faster than 10ms, yield the remainder.
    // elapsedMillis-based approach: do NOT delay if sensors/comms already took > 10ms.
    if (loopTimer < 10) {
        // busy-wait the remainder so we don't skip a sensor poll cycle
        while (loopTimer < 10);
    }
    loopTimer = 0;
}

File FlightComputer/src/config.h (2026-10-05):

#pragma once

// =============================================================
// config.h — All pin definitions and flight constants
// Derived from KiCad schematics (main.kicad_sch and sub-sheets)
// Board: Custom RocketPower PCB (NXP MIMXRT1062), programmed via the
// Teensy 4.1 toolchain/bootloader -- not a Teensy dev board.
// =============================================================

// ===== Debug/diagnostic text output =====
// Bench diagnostic prints (loop/sensor/GPS/SD timing breakdowns) used to
// share the normal `Serial` USB port with the binary telemetry mirror,
// which is exactly why bench serial-monitor captures came out full of
// garbled control characters -- human text and raw binary packets
// interleaved on the same byte stream, and neither a plain terminal nor
// GroundStation's own packet parser can tell them apart mid-stream.
// SerialUSB1 (Teensy's second USB CDC port, enabled via -DUSB_DUAL_SERIAL
// in platformio.ini) carries ONLY this plain text instead, so `Serial`
// stays purely binary telemetry + command RX, and GroundStation's Test tab
// can show this stream directly without fighting the packet decoder for it.
// HITL_MODE already claims SerialUSB1 for the actual sensor-injection
// protocol (see platformio.ini's [env:rocketpower_hitl] comment) -- debug
// text falls back to plain Serial there instead, same as before this change.
#ifdef HITL_MODE
    #define DEBUG_SERIAL Serial
#else
    #define DEBUG_SERIAL SerialUSB1
#endif

// ===== I2C Bus Assignments =====
// Wire  (LPI2C1, pins 18 SDA / 19 SCL): sensors with no bus-number suffix
// Wire1 (LPI2C3, pins 17 SDA / 16 SCL): sensors labelled _SDA1 / _SCL1
// Wire2 (LPI2C4, pins 25 SDA / 24 SCL): sensors labelled _SDA2 / _SCL2

#define BNO085_I2C_BUS   Wire
#define BNO085_I2C_ADDR  0x4A   // SA0 pulled LOW (BNO085_SCL/SDA, no suffix)

#define BMP390_I2C_BUS   Wire1
#define BMP390_I2C_ADDR  0x77   // SDO pulled HIGH (BMP390_SCL1/SDA1)

#define ZOEM8_I2C_BUS    Wire1
#define ZOEM8_I2C_ADDR   0x42   // fixed u-blox DDC address (ZOEM8_SCL1/SDA1)

#define INA260_I2C_BUS   Wire1
#define INA260_I2C_ADDR  0x40   // A0=A1=GND (INA260_SCL1/SDA1)

#define ADXL375_I2C_BUS  Wire2
#define ADXL375_I2C_ADDR 0x1D   // CS tied HIGH, ADDR tied HIGH (ADXL375_SCL2/SDA2)

// ===== IMU mounting-offset calibration =====
// BENCH-CONFIRMED (2026-09): the BNO085's rotation vector reports a fixed
// ~8 deg tilt even with the airframe verified vertical (level/plumb-line
// checked, not just eyeballed), stable across power cycles, different
// headings, and both low- and high-confidence sensor-hub states (rvStatus
// in [IMU RAW] -- see IMU.cpp) -- ruling out sensor noise, calibration
// convergence, and LoRa rail coupling in turn. This is a real, constant
// mechanical misalignment between the BNO085's sensing axes and the
// airframe's true centerline (breakout-to-PCB mount or chip-package
// tolerance -- exact source doesn't matter, only that it's fixed).
//
// This matters beyond the tilt readout: AttitudeController's roll/pitch
// angle error is computed directly off the SAME uncorrected quaternion
// (see its "targets true vertical directly" comment) -- left uncorrected,
// a straight-flying rocket would get a constant, wrong fin correction the
// entire powered-ascent/coast phase.
//
// IMU_MOUNT_CAL_QUAT_* is the RAW quaternion (w,x,y,z) read from [IMU RAW]
// with the airframe verified vertical and steady -- pick a sample with
// rvStatus=3 if possible. IMU::_applyEvent() rotates every subsequent
// rotation-vector reading by this quaternion's inverse, so a reading
// identical to this reference collapses to tilt=0/yaw=0 exactly, while a
// real dynamic tilt during flight still measures correctly against true
// vertical (this is a FIXED hardware calibration constant, not a per-arm
// re-latch -- unlike AttitudeController's yaw reference, which
// intentionally IS re-latched at engage since heading has no absolute
// reference to begin with).
//
// TO RECALIBRATE (mount changed, or drifted with time/vibration): verify
// the airframe is truly vertical (level/plumb-line against the airframe,
// not the breakout board), reflash with these 4 values left at their old
// setting first, capture one fresh still [IMU RAW] q=(...) line (ideally
// one tagged rvStatus=3), and paste its 4 numbers in below.
#define IMU_MOUNT_CAL_QUAT_W   0.9841f
#define IMU_MOUNT_CAL_QUAT_X  -0.0215f
#define IMU_MOUNT_CAL_QUAT_Y   0.0665f
#define IMU_MOUNT_CAL_QUAT_Z   0.1631f

// Echo raw NMEA sentences to DEBUG_SERIAL as they're read (verbose — GPS bring-up only)
#define GPS_DEBUG_RAW_NMEA 0

// ===== UART Assignments =====
// From schematic text annotations: "0 (RX1)", "1 (TX1)", "RX 28", "TX 29"
#define LORA_SERIAL      Serial1   // Lora_TX→pin0 (RX1), Lora_RX→pin1 (TX1)
#define LORA_BAUD        9600

#define CAM_SERIAL       Serial7   // Cam_TX→pin28 (RX7), Cam_RX→pin29 (TX7)
#define CAM_BAUD         115200
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

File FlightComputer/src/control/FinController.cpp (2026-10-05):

#include "FinController.h"
#include "../config.h"
#include <Arduino.h>
#include <EEPROM.h>
#include <math.h>

const uint8_t FinController::_pins[SERVO_NUM_CHANNELS] = {
    SERVO1_PIN, SERVO2_PIN, SERVO3_PIN, SERVO4_PIN,
};

struct FinCalibration {
    uint8_t magic;
    int16_t trimUs[SERVO_NUM_CHANNELS];
};

bool FinController::begin() {
    _loadCalibration();

    // Stagger each channel's first command instead of firing all 4 at once --
    // spreads inrush current on the shared, unregulated servo rail instead of
    // stacking it. See SERVO_INIT_STAGGER_MS in config.h.
    for (int i = 0; i < SERVO_NUM_CHANNELS; i++) {
        if (FIN_TEST_SKIP_CHANNEL == i + 1) {
            DEBUG_SERIAL.print("[FIN] ch"); DEBUG_SERIAL.print(i + 1);
            DEBUG_SERIAL.println(" left unattached (FIN_TEST_SKIP_CHANNEL)");
            continue;
        }
        _servos[i].attach(_pins[i]);
        _writeUs(i, (int32_t)SERVO_CENTER_US + _trimUs[i]);
        delay(SERVO_INIT_STAGGER_MS);
    }
    return true;
}

void FinController::_loadCalibration() {
    FinCalibration cal;
    EEPROM.get(SERVO_CAL_EEPROM_ADDR, cal);
    if (cal.magic != SERVO_CAL_MAGIC) {
        DEBUG_SERIAL.println("[FIN] No saved calibration -- starting at center.");
        for (int i = 0; i < SERVO_NUM_CHANNELS; i++) _trimUs[i] = 0;
        return;
    }
    for (int i = 0; i < SERVO_NUM_CHANNELS; i++) _trimUs[i] = cal.trimUs[i];
    DEBUG_SERIAL.println("[FIN] Loaded calibration from EEPROM.");
}

void FinController::_writeUs(uint8_t idx, int32_t us, int32_t loUs, int32_t hiUs) {
    if (us < loUs) us = loUs;
    if (us > hiUs) us = hiUs;
    _liveUs[idx] = (uint16_t)us;
    _servos[idx].writeMicroseconds(_liveUs[idx]);
}

void FinController::_symmetricFlightLimits(uint8_t idx, int32_t& loUs, int32_t& hiUs) const {
    int32_t center = (int32_t)SERVO_CENTER_US + _trimUs[idx];
    int32_t marginDown = center - SERVO_MIN_US;
    int32_t marginUp   = SERVO_MAX_US - center;
    int32_t symMarginUs = (marginDown < marginUp) ? marginDown : marginUp;
    loUs = center - symMarginUs;
    hiUs = center + symMarginUs;
}

void FinController::setCorrectionDeg(uint8_t channel, float correctionDeg) {
    if (channel < 1 || channel > SERVO_NUM_CHANNELS) return;
    uint8_t idx = channel - 1;
    int32_t center = (int32_t)SERVO_CENTER_US + _trimUs[idx];

    // SERVO_MIN_US/MAX_US are measured from the MECHANICAL center, not this
    // channel's trimmed center -- so a nonzero trim leaves unequal room each
    // direction before that absolute limit (see _symmetricFlightLimits).
    // Clamp to the SAME distance from center both ways so a commanded
    // +/-X deg always produces matched real authority, same reasoning
    // (and now the same fix) as testSweep()/preflightSequence().
    int32_t loUs, hiUs;
    _symmetricFlightLimits(idx, loUs, hiUs);

    // Same us-per-degree scale as SERVO_MIN_US/SERVO_MAX_US in config.h
    // (800us / 90deg on the BMS-101HV datasheet).
    int32_t correctionUs = (int32_t)lroundf(800.0f * correctionDeg / 90.0f);
    int32_t us = center + correctionUs;
    if (us < loUs) us = loUs;
    if (us > hiUs) us = hiUs;

    _writeUs(idx, us);   // still hard-clamped to SERVO_MIN_US/MAX_US in here as a backstop
}

void FinController::_symmetricSweepLimits(uint8_t idx, int32_t& loUs, int32_t& hiUs) const {
    int32_t center = (int32_t)SERVO_CENTER_US + _trimUs[idx];
    int32_t sweepUs    = (int32_t)lroundf(800.0f * SERVO_TEST_SWEEP_ANGLE_DEG / 90.0f);
    int32_t marginDown = center - SERVO_RATED_MIN_US;
    int32_t marginUp   = SERVO_RATED_MAX_US - center;
    int32_t symMarginUs = sweepUs;
    if (symMarginUs > marginDown) symMarginUs = marginDown;
    if (symMarginUs > marginUp)   symMarginUs = marginUp;
    loUs = center - symMarginUs;
    hiUs = center + symMarginUs;
}

void FinController::testSweep(uint8_t channel) {
    if (channel < 1 || channel > SERVO_NUM_CHANNELS) return;
    uint8_t idx = channel - 1;
    int32_t center = (int32_t)SERVO_CENTER_US + _trimUs[idx];
    int32_t loUs, hiUs;
    _symmetricSweepLimits(idx, loUs, hiUs);

    DEBUG_SERIAL.print("[FIN] Test sweep ch"); DEBUG_SERIAL.println(channel);
    _writeUs(idx, center, SERVO_RATED_MIN_US, SERVO_RATED_MAX_US);  delay(SERVO_TEST_STEP_MS);
    _writeUs(idx, loUs,   SERVO_RATED_MIN_US, SERVO_RATED_MAX_US);  delay(SERVO_TEST_STEP_MS);
    _writeUs(idx, hiUs,   SERVO_RATED_MIN_US, SERVO_RATED_MAX_US);  delay(SERVO_TEST_STEP_MS);
    _writeUs(idx, center, SERVO_RATED_MIN_US, SERVO_RATED_MAX_US);  delay(SERVO_TEST_STEP_MS);
    DEBUG_SERIAL.print("[FIN] ch"); DEBUG_SERIAL.print(channel); DEBUG_SERIAL.println(" complete");
}

void FinController::_rampTo(uint8_t idx, int32_t targetUs, uint32_t durationMs, int32_t loUs, int32_t hiUs) {
    const uint8_t steps = 20;
    int32_t startUs = (int32_t)_liveUs[idx];
    uint32_t stepDelay = durationMs / steps;
    for (uint8_t s = 1; s <= steps; s++) {
        _writeUs(idx, startUs + (targetUs - startUs) * (int32_t)s / steps, loUs, hiUs);
        delay(stepDelay);
    }
}

void FinController::_rampAllTo(const int32_t targets[SERVO_NUM_CHANNELS], uint32_t durationMs, int32_t loUs, int32_t hiUs) {
    const uint8_t steps = 20;
    int32_t startUs[SERVO_NUM_CHANNELS];
    for (int i = 0; i < SERVO_NUM_CHANNELS; i++) startUs[i] = (int32_t)_liveUs[i];
    uint32_t stepDelay = durationMs / steps;
    for (uint8_t s = 1; s <= steps; s++) {
        for (int i = 0; i < SERVO_NUM_CHANNELS; i++) {
            _writeUs(i, startUs[i] + (targets[i] - startUs[i]) * (int32_t)s / steps, loUs, hiUs);
        }
        delay(stepDelay);
    }
}
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

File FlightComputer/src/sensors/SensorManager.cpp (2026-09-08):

#include "SensorManager.h"
#include "../config.h"
#include "../DebugPrint.h"
#include <Wire.h>
#include <math.h>
#include <string.h>

#ifdef HITL_MODE

bool SensorManager::_hitlReadPacket(SensorInjectPacket& out, uint32_t timeoutMs) {
    uint8_t buf[sizeof(SensorInjectPacket)];
    size_t  have = 0;
    uint32_t deadline = millis() + timeoutMs;
    while ((int32_t)(deadline - millis()) > 0) {
        if (SerialUSB1.available() == 0) continue;
        uint8_t b = (uint8_t)SerialUSB1.read();
        if (have == 0) {
            if (b != HITL_SENSOR_MAGIC_0) continue;
            buf[have++] = b;
        } else if (have == 1) {
            if (b != HITL_SENSOR_MAGIC_1) { have = 0; continue; }
            buf[have++] = b;
        } else {
            buf[have++] = b;
            if (have == sizeof(SensorInjectPacket)) {
                uint16_t expected = packetChecksum(buf, sizeof(SensorInjectPacket) - 2);
                uint16_t stored;
                memcpy(&stored, buf + sizeof(SensorInjectPacket) - 2, 2);
                if (expected == stored) {
                    memcpy(&out, buf, sizeof(SensorInjectPacket));
                    return true;
                }
                have = 0;   // bad checksum -- resync from scratch, don't get stuck out of frame
            }
        }
    }
    return false;   // timed out -- caller falls back to _lastHitlPkt
}

bool SensorManager::begin() {
    Serial.println("[SENSOR] HITL_MODE build -- sensors are SIMULATED, injected over SerialUSB1.");
    SerialUSB1.begin(115200);   // baud is ignored by Teensy's native USB CDC; kept for host-side portability

    // No real hardware to probe -- report healthy so boot doesn't halt on
    // the imu_ok/baro_ok gate below. gps/power aren't modeled by the bridge;
    // nothing flight-critical gates on those two (see SENSOR_HEALTH_TIMEOUT_MS
    // in config.h), so leaving them "unhealthy" is honest and harmless.
    _data.imu_ok = _data.baro_ok = _data.accel_ok = true;
    _data.gps_ok = _data.power_ok = false;

    // Safe default until the very first real packet arrives -- "resting on
    // the pad": identity orientation, zero rates, ~1g on highg_z (matches
    // what a real accelerometer reads sitting still). See update()/the note
    // on _lastHitlPkt in the header for why this matters: it's what keeps
    // the loop (and telemetry) running normally before a HITL bridge is
    // actually connected, instead of the whole build silently hanging on
    // the first sensors.update() call.
    _lastHitlPkt = SensorInjectPacket{};
    _lastHitlPkt.quat_w   = 1.0f;
    _lastHitlPkt.highg_z  = 1.0f;
    _hasHitlPacket = false;

    return true;
}

void SensorManager::update() {
    SensorInjectPacket pkt;
    // 20ms: comfortably longer than a real bridge round-trip (sub-ms to a
    // few ms over USB), short enough that the loop still heartbeats at a
    // reasonable rate (~50Hz) while idle/unconnected. See the header note
    // on _hitlReadPacket/_lastHitlPkt for why this can't just block forever.
    if (_hitlReadPacket(pkt, 20)) {
        _lastHitlPkt   = pkt;
        _hasHitlPacket = true;
    }
    const SensorInjectPacket& src = _lastHitlPkt;

    _data.timestamp_ms = millis();

    _data.quat_w = src.quat_w; _data.quat_x = src.quat_x;
    _data.quat_y = src.quat_y; _data.quat_z = src.quat_z;
    _data.gyro_x = src.gyro_x; _data.gyro_y = src.gyro_y; _data.gyro_z = src.gyro_z;
    _data.lin_accel_x = src.lin_accel_x;
    _data.lin_accel_y = src.lin_accel_y;
    _data.lin_accel_z = src.lin_accel_z;
    _data.accel_mag_ms2 = sqrtf(src.lin_accel_x * src.lin_accel_x +
                                 src.lin_accel_y * src.lin_accel_y +
                                 src.lin_accel_z * src.lin_accel_z);

    _data.highg_x_g = src.highg_x; _data.highg_y_g = src.highg_y; _data.highg_z_g = src.highg_z;
    _data.highg_mag_g = sqrtf(src.highg_x * src.highg_x + src.highg_y * src.highg_y + src.highg_z * src.highg_z);

    _data.baro_alt_m  = src.baro_alt_m;
    _data.vert_vel_ms = src.vert_vel_ms;   // sim ground truth -- the real build's complementary filter isn't compiled into this path at all

    // Not modeled by the HITL bridge -- zeroed, harmless (see begin()'s note
    // on gps_ok/power_ok; nothing flight-critical reads these otherwise).
    _data.pressure_hpa = 0.0f; _data.temperature_c = 0.0f;
    _data.lat = 0.0; _data.lon = 0.0; _data.gps_alt_m = 0.0f; _data.gps_sats = 0; _data.gps_fix = false;
    _data.voltage_v = 0.0f; _data.current_ma = 0.0f; _data.power_mw = 0.0f;
}

void SensorManager::calibrateBaro() {
    // No physical baro to zero -- the bridge already sends pad-relative
    // altitude directly (see Simulation/hitl/). No-op.
}

#else
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

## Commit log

2024-10-04 First commit, this is my first version of the flight computer pcb design only with what is nesseray to make the MIMXRT106DVL6B MCU work
    [main.kicad_pcb, main.kicad_sch, main1.kicad_sch]
2024-10-12 Added the ADXL375 AND BMP390 to the schematic, next step is gps and sdcard holder
    [ADXL375.kicad_sch, BMP390.kicad_sch, BNO085.kicad_sch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]
2024-10-15 Added a few sensors schematics like multiplex for i2c comms, current/voltage sensor, micro sd slot, more to go!
    [BMP390.kicad_sch, INA260.kicad_sch, TCA9548A.kicad_sch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]
2024-10-24 Well I added a bunch of sensors, some connectors for battery, pyro channels mosfets, etc
    [ADXL375.kicad_sch, BMP390.kicad_sch, BNO085.kicad_sch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]
2025-09-14 Addition of telemetry is pcb schematic
    [ADXL375.kicad_sch, BMP390.kicad_sch, BNO085.kicad_sch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]
2025-12-22 The design is getting more mature, still did not choose if doing 4 layers or 2 layers pcb, will try to add 5v for a on board camera and trace routes for reserved pins in case of usage on another vehi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
    [ADXL375.kicad_sch, BMP390.kicad_sch, BNO085.kicad_sch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]
2025-12-26 Reserved and camera sheets
    [Camera.kicad_sch, Reserved.kicad_sch, main.kicad_pcb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]
2025-12-28 Camera and reserve
    [Camera.kicad_sch, HighCurrentComponents.kicad_sch.kicad_sch, INA260.kicad_sch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]
2025-12-29 CID documentation and started the PCB editor process
    [Avionics-Electrical-CID-Rev00.xlsx, Camera.kicad_sch, HighCurrentComponents.kicad_sch.kicad_sch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]
2026-02-02 Layout of PCB mostly done
    [ADXL375.kicad_sch, Avionics-Electrical-CID-Rev00.xlsx, BMP390.kicad_sch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]
2026-02-03 Preliminary layout done but need to rearrange sd card and such to have the best routing
    [830050789.stp, BNO085.kicad_sch, main.kicad_pcb]
2026-02-04 Routing pcb
    [BNO085.kicad_sch, main.kicad_pcb, main.kicad_sch]
2026-03-11 Addition of teensy example and milestone on routing completed, missing a few components to connect
    [BNO085.kicad_sch, Camera.kicad_sch, HighCurrentComponents.kicad_sch.kicad_sch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]
2026-03-12 First iteration of layout finished, we could call this v0, congratulations! Need an expert to state if layer 4 and layer 3 interations are ok (pwm/ psram/i2c/uart vs power plane 7.5v and 3.3v )
    [INA260.kicad_sch, main.kicad_pcb, main.kicad_sch]
2026-03-12 PR1; Fix PSRAM length of data, clock and cs pins to match since high speed data transmission, needs to be within 0.5mm trace length delta
    [main.kicad_pcb, telemetry.kicad_sch]
2026-03-15 First pass of verification and validation of pcb design
    [ADXL375.kicad_sch, BMP390.kicad_sch, BNO085.kicad_sch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]
2026-03-25 Layout changes to incorporate power capacitors for the servos
    [EMZR160ARA102MJA0G.stp]
2026-03-28 Addition of all components in BOM, metal mounting plates, need to check psram if its ok for signals to pass under, all components need a double check
    [A750EQ477M1CAAE015.stp, ADXL375.kicad_sch, BMP390.kicad_sch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]
2026-03-31 Last commit before changing bga to trace clearance of 6mils
    [Reserved.kicad_sch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]
2026-04-01 First commit with 0.1mm traces and 02mm by 0.43mm vias to fit pcbway standard manufacturing + corrections of PR'S like uart RX of component to TX of mcu
    [BNO085.kicad_sch, INA260.kicad_sch, main.kicad_pcb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]
2026-04-13 Switch to KICAD10 and correction of TX RX
    [main.kicad_pcb]
2026-04-22 Change of winbond flash to other one supported by teensy bootloader since winbond is out of stock
    [ADXL375.kicad_sch, BMP390.kicad_sch, BNO085.kicad_sch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]
2026-05-07 Final verification started, schematic verification of USBC and High current components
    [HighCurrentComponents.kicad_sch.kicad_sch, main.kicad_pcb, main.kicad_sch]
2026-05-17 Corrected a few subsystems
    [ADXL375.kicad_sch, BNO085.kicad_sch, HighCurrentComponents.kicad_sch.kicad_sch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]
2026-05-17 Corrections of mistake, revision of schematic is done and BOM revised, revision of pcb layout to do
    [ADXL375.kicad_sch, BMP390.kicad_sch, BNO085.kicad_sch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]
2026-05-17 Because i am lazy i would call this the V1 of the avionics
    [ABS06-32.768KHZ-9-1-T.stp, main.kicad_pcb, main.kicad_sch]
2026-05-18 Was missing pull ups on adxl375
    [ADXL375.kicad_sch, HighCurrentComponents.kicad_sch.kicad_sch, ZOEM8.kicad_sch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]
2026-05-19 REVA board?
    [Camera.kicad_sch, HighCurrentComponents.kicad_sch.kicad_sch, main.kicad_pcb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]
2026-05-22 Addition of logos silkscreen
    [main.kicad_pcb]
2026-05-22 Logo update
    [main.kicad_pcb, main.kicad_pcb_bom.csv, main.kicad_pcb_positions.csv]
2026-06-29 First Attempt to ground station code, flight computer code and correction for revB PCB (reset button)
    [1548130.stp, 2.54mm.stp, 830050789.stp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]
2026-07-01 First iteration of simulator, next steps will be to input cad (simscape), add fins control actuation and moment impact
    [log_2026-06-28_23-25-21.csv, log_2026-06-28_23-25-24.csv, log_2026-06-28_23-25-27.csv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]
2026-08-04 Servos, camera and telemetry connection (telemetry needs work, only one way comms for now)
    [log_2026-07-13_11-51-44.csv, log_2026-07-13_12-06-20.csv, log_2026-07-13_12-06-22.csv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]
2026-08-05 Telemetry working fine at 1hz
    [log_2026-06-29_16-52-02.csv, log_2026-06-29_16-58-20.csv, log_2026-06-29_16-58-49.csv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]
2026-08-05 Telemetry and Camera works well! Still imited to 1hz tho
    [log_2026-08-04_22-09-36.csv]
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2026-08-07 SD Card flight data tool to transfer .bin to .csv
    [rocket.stl]
2026-08-07 Amelioration of GUI and setup of in flight boot mode in case of computer reset
    [BackupDeploy.cpp, PyroController.cpp, config.h]
2026-08-15 Simulation works as expected, physical properties need to be input now to get PID gains + animation modeled for visual verification
2026-08-31 First commit with AI less code for flight computer, lets take our time to build the flight control code, first will be with helping library, next step will be RTOS bare metal firmware
    [Avionics-Electrical-CID-Rev00.xlsx]
2026-09-02 Code for BNO085 done, functions like begin() and update to get IMU data
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2026-09-06 Fix .gitignore anchoring/suffix gaps missed by the previous cleanup
    *.bak (dot-suffix) files and PCB/main/production/backups/ (nested, not
    root-level) weren't actually matched by the patterns added in 43ffcf7/
    89e85a7, so they still showed up as untracked clutter after untracking.
    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
2026-09-08 Fix of PR's and documentation
    [Accelerometer.cpp, BackupDeploy.cpp, Barometer.cpp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]
2026-10-02 Modification of PID gains that work with HITL test but are way too slow. Trying to find out the issue
    [AttitudeController.cpp, Packet.h, TelemetryManager.cpp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]
2026-10-05 Correction of max rotation of fins according to offset + max angle 30 deg and Kd are 0 to record a demo, to change later on
    [AttitudeController.cpp, FinController.cpp, config.h]

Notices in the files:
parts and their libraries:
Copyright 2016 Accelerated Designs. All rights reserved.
